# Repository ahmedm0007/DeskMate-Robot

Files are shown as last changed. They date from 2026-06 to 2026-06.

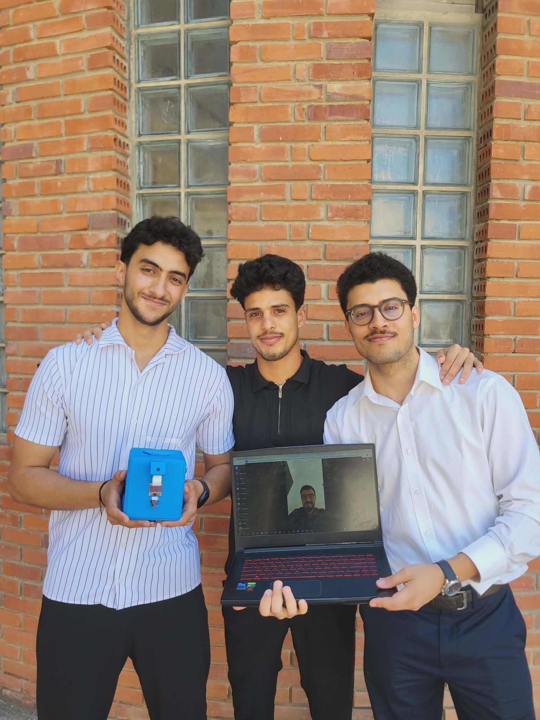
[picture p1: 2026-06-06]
our pic.jpg

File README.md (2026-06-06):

# 🤖 DeskMate — Intelligent Study Assistant Robot

> A physical desktop robot that monitors student concentration in real time, detects distraction and fatigue, and provides personalized academic assistance through voice interaction and AI-powered document Q&A.

---

## 📌 Overview

DeskMate is an end-of-year engineering project built at **INSAT** (National Institute of Applied Science and Technology, Tunis). It addresses a concrete problem: study sessions are rarely as effective as they should be. Students get distracted, lose focus, and have no tool that actively intervenes.

DeskMate is a **physical companion robot** — present on your desk like a lamp — that observes, analyzes, and acts. Unlike passive apps, it adapts its behavior in real time to the student's actual state.

---

## ✨ Features

### 👁️ Behavioral Monitoring (Vision Pipeline)
- **Real-time face detection** and multi-user recognition (MediaPipe + ArcFace/DeepFace)
- **Fatigue detection** via Eye Aspect Ratio (EAR) and Mouth Aspect Ratio (MAR)
- **Distraction detection**: gaze direction (head pose estimation) + smartphone detection (YOLOv8)
- **Absence detection**: alerts when the student leaves the camera field
- Runs at **~30 FPS** on Raspberry Pi 4, well within the 500ms real-time constraint

### 🗣️ Voice Interaction (Vocal Pipeline)
- **Wake word detection** (local, via Vosk) → **Speech-to-Text** (Google Web Speech API)
- **LLM-powered intent classification** and conversational responses (Qwen2.5-7B-Instruct via Hugging Face API)
- **Text-to-Speech** output (edge_tts + pygame) with ~0.8s generation time
- End-to-end latency: **2–4 seconds** for a complete voice exchange

### 📚 Academic AI Assistant (RAG System)
- Upload your own **PDF course documents**
- Hybrid search: **semantic (ChromaDB)** + **keyword (BM25)** retrieval
- Answers generated by **Gemini 2.5 Flash**, grounded exclusively in your documents
- Evaluation results: **85% answer correctness**, 87.5% hit rate on test corpus

### 📅 Adaptive Study Planner
- Input your subjects, mastery level, exam dates, and available hours
- Generates a **personalized weekly revision schedule** using a priority scoring model
- Urgency factor recalculated daily as exams approach
- Subjects automatically removed after their exam date

### 📊 Session Management & Dashboard
- Supports **Pomodoro**, **Deep Work**, and **52/17** productivity techniques
- Voice-controlled session start/pause/stop
- OLED display shows current state (focused / distracted / break / session end)
- **React/Next.js web dashboard** (localhost): session history, productivity graphs, planning, PDF upload

### 🚗 Autonomous Mobility
- **Differential drive** (2× GA12-N20 motors) controlled by ESP32
- **ToF sensor (VL53L0X)** for desk-edge detection and collision avoidance
- Autonomous repositioning to keep the student in camera frame

---

## 🏗️ System Architecture

```
┌─────────────────────────────────────────────────────┐
│            LAYER 1 — Perception                     │
│   Pi Camera 8MP | INMP441 Mic (I2S) | ToF VL53L0X  │
└────────────────────┬────────────────────────────────┘
                     │
┌────────────────────▼────────────────────────────────┐
│          LAYER 2 — AI Processing                    │
│  OpenCV + YOLOv8 + MediaPipe (Vision)               │
│  Vosk + Google STT (Speech)                         │
│  LLM (Qwen2.5) + RAG (LangChain + ChromaDB)         │
└────────────────────┬────────────────────────────────┘
                     │
┌────────────────────▼────────────────────────────────┐
│       LAYER 3 — Decision & Orchestration            │
│       FastAPI — State machine | Scheduler | Rules   │
└────────────────────┬────────────────────────────────┘
                     │
┌────────────────────▼────────────────────────────────┐
│            LAYER 4 — Actuators                      │
│    GA12-N20 Motors | OLED SSD1306 | Speaker (TTS)   │
└────────────────────┬────────────────────────────────┘
                     │
┌────────────────────▼────────────────────────────────┐
│         LAYER 5 — User Interface (localhost)        │
│         React / Next.js + Tailwind CSS              │
│   History | Charts | Planning | PDF Upload | Profiles│
└─────────────────────────────────────────────────────┘
```

---

## 🔧 Hardware

| Component | Role |
|---|---|
| Raspberry Pi 4 (4GB) | Main brain — runs all AI/software modules |
| ESP32 | Spinal cord — real-time actuator control |
| Pi Camera Module V2 (8MP) | Vision pipeline input |
| INMP441 Microphone (I2S) | Voice capture |
| MAX98357A Amplifier + 8Ω Speaker | TTS audio output |
| OLED Display SSD1306 (0.96") | Real-time status display |
| ToF Sensor VL53L0X | Desk-edge detection |
| 2× GA12-N20 DC Motors + TB6612FNG | Differential drive |
| 2× 18650 Li-ion (3000 mAh) + XL4015 Buck | Power supply (~2.5–3.5h autonomy) |
| 3D-printed PLA chassis | 3-level structure, custom-designed |

---

## 💻 Tech Stack

**AI & Vision**
`OpenCV` `MediaPipe` `YOLOv8` `DeepFace (ArcFace)` `LangChain` `ChromaDB` `BM25` `Gemini 2.5 Flash` `Qwen2.5-7B`

**Speech**
`Vosk` `Google Web Speech API` `edge_tts` `pygame`

**Backend**
`FastAPI` `Python 3.10+` `SQLite` `PostgreSQL`

**Frontend**
`React 19` `Next.js` `TypeScript` `Tailwind CSS v4` `Recharts` `Vite`

**Embedded**
`Raspberry Pi OS` `ESP32 (Arduino)` `pigpio` `I2C` `I2S` `UART` `PWM`

**Design**
`SolidWorks` (3D chassis) `KiCad` (PCB schematic)

---

## 📈 Performance Results

| Module | Metric | Result |
|---|---|---|
| Vision pipeline | Processing speed | ~30 FPS on RPi 4 |
| Behavioral detection | Latency | < 500ms ✅ |
| Face recognition (ArcFace) | Accuracy | > 99% |
| Phone detection (YOLOv8) | mAP@50 | 52.1% (+ temporal smoothing) |
| RAG system | Answer correctness | 85.0% |
| RAG system | Hit rate | 87.5% |
| Voice pipeline | End-to-end latency | 2–4 seconds |
| TTS (edge_tts) | Generation time | ~0.8 seconds |

---

## 👥 Team

| Name | Role |
|---|---|
| **MAMI Ahmed** | Embedded systems, hardware design, mechanical conception |
| **ZGHIBI Ahmed** | AI pipeline, system integration |
| **EL KADHI Mohamed Amine** | Vision & RAG modules |
| **ZNAGUI Wael** | Backend & dashboard |

**Supervisor:** Mme JAAFAR Imen  
**Institution:** INSAT — 4th year, Industrial Computing and Automation  
**Defended:** June 1st, 2026

---

## 📄 License

This project was developed as an academic end-of-year project at INSAT, Tunis. All rights reserved by the authors.

## 🗂️ Mechanical Files (SolidWorks)

Full 3D assembly and parts (SolidWorks + STL) are too large for GitHub.  
👉 [Download 3D Files (Google Drive)] https://drive.google.com/drive/folders/134jamOGdysIHbzPeDwZQ4sSwSuv-kNpy?usp=sharing

Includes:
- Full robot assembly (RobotAssemblageV1.SLDASM)
- All individual parts (SLDPRT)
- STL files for 3D printing
- KiCad PCB schematic

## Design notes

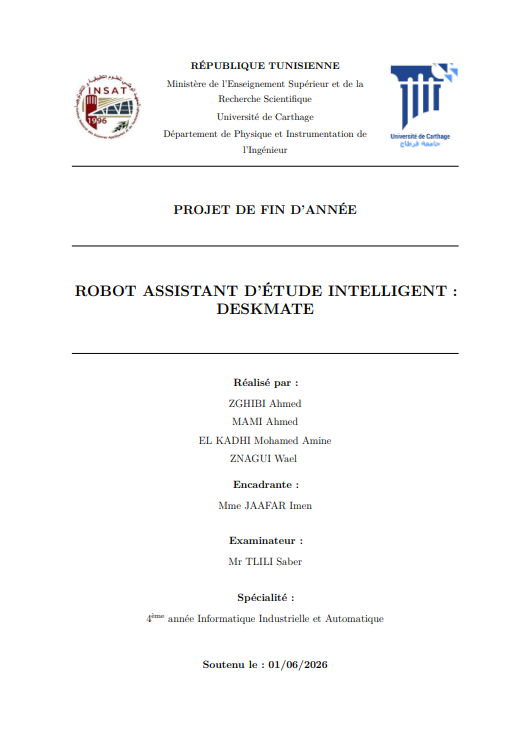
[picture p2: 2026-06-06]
firstRapportPage.png

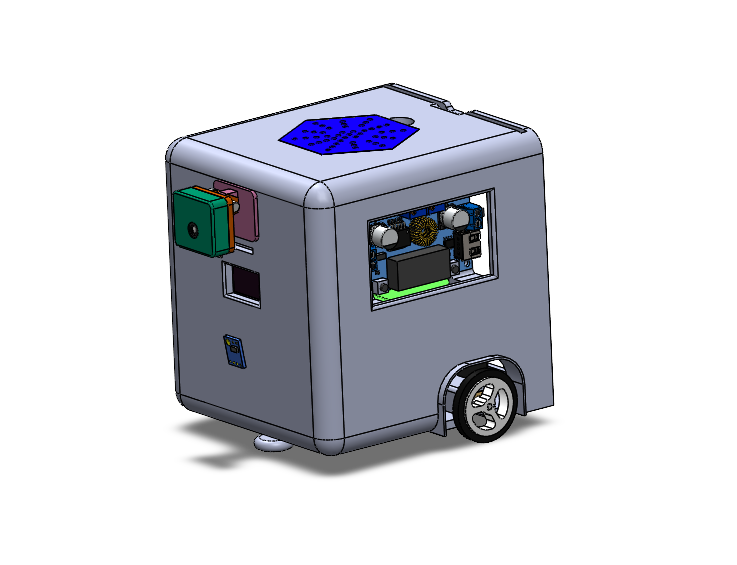
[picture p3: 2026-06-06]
RobotPIC.png

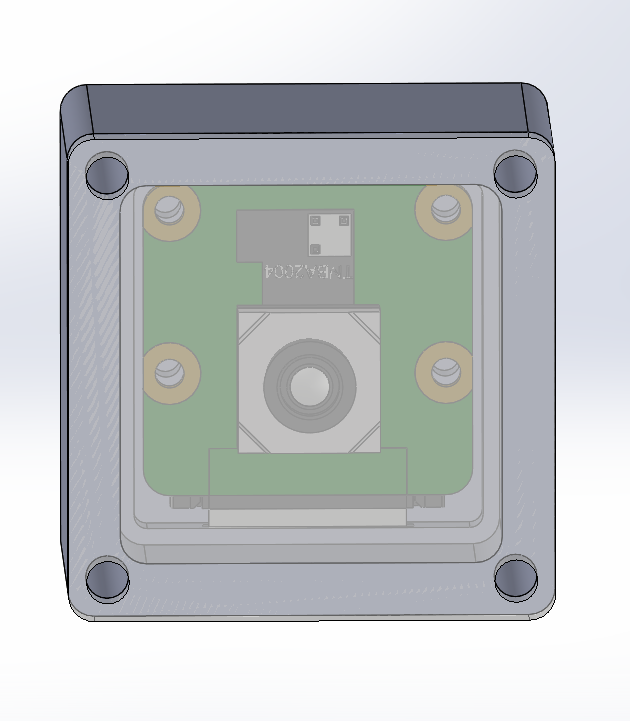
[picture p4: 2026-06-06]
MECANIQUE/picam holder/Screenshot 2025-12-24 074149.png

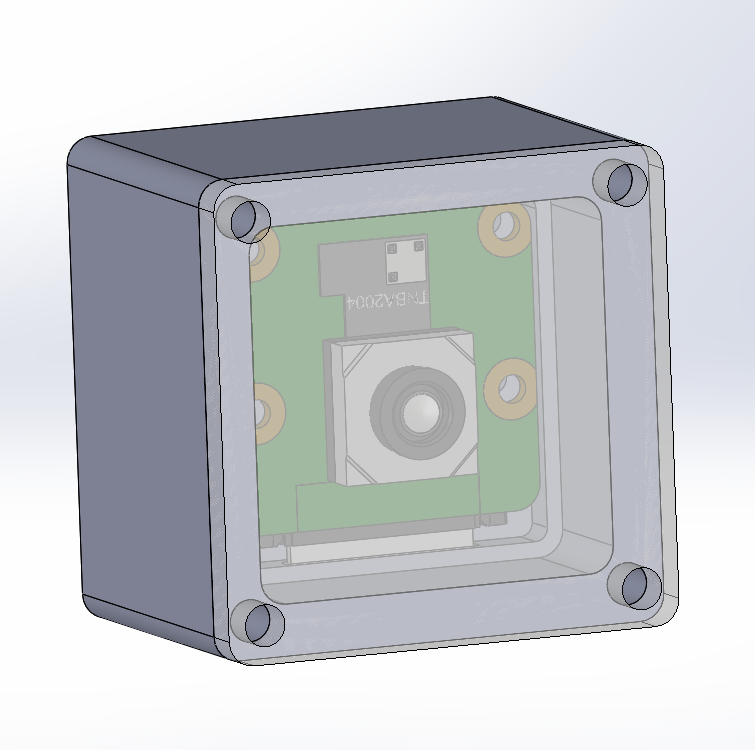
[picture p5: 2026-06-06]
MECANIQUE/picam holder/Screenshot 2025-12-24 074029.png

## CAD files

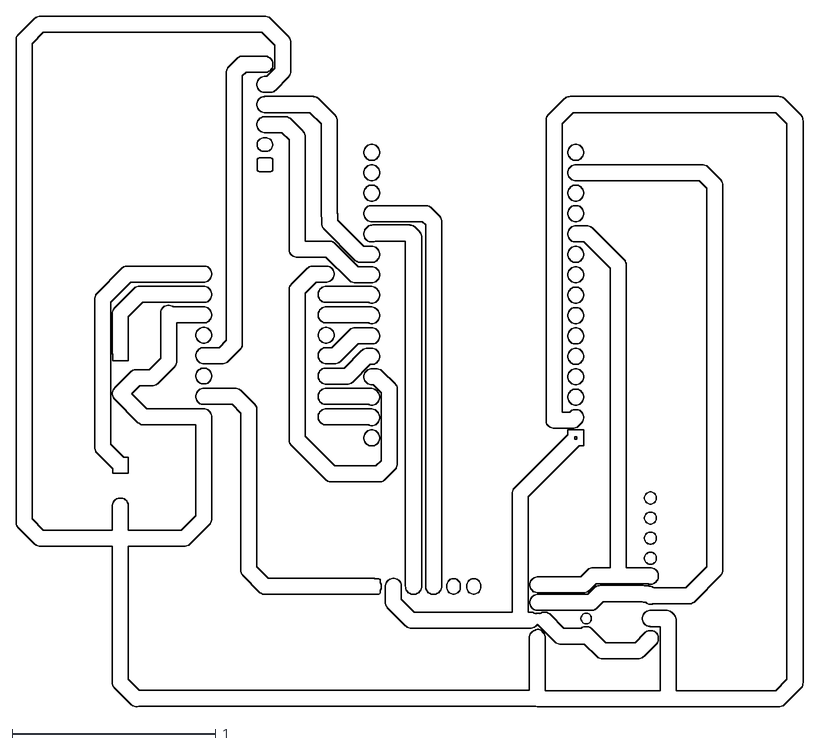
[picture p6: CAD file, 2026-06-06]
ELECTRIQUE/chimiqueV0/chimiqueV0-F_Cu.dxf
3.86 x 3.39

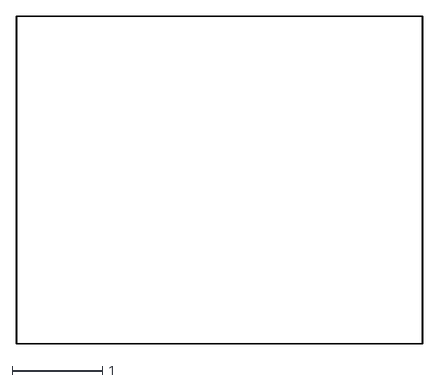
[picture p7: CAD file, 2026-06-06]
ELECTRIQUE/chimiqueV0/chimiqueV0-Edge_Cuts.dxf
4.49 x 3.62

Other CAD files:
ELECTRIQUE/chimiqueV0/chimiqueV0-Margin.dxf

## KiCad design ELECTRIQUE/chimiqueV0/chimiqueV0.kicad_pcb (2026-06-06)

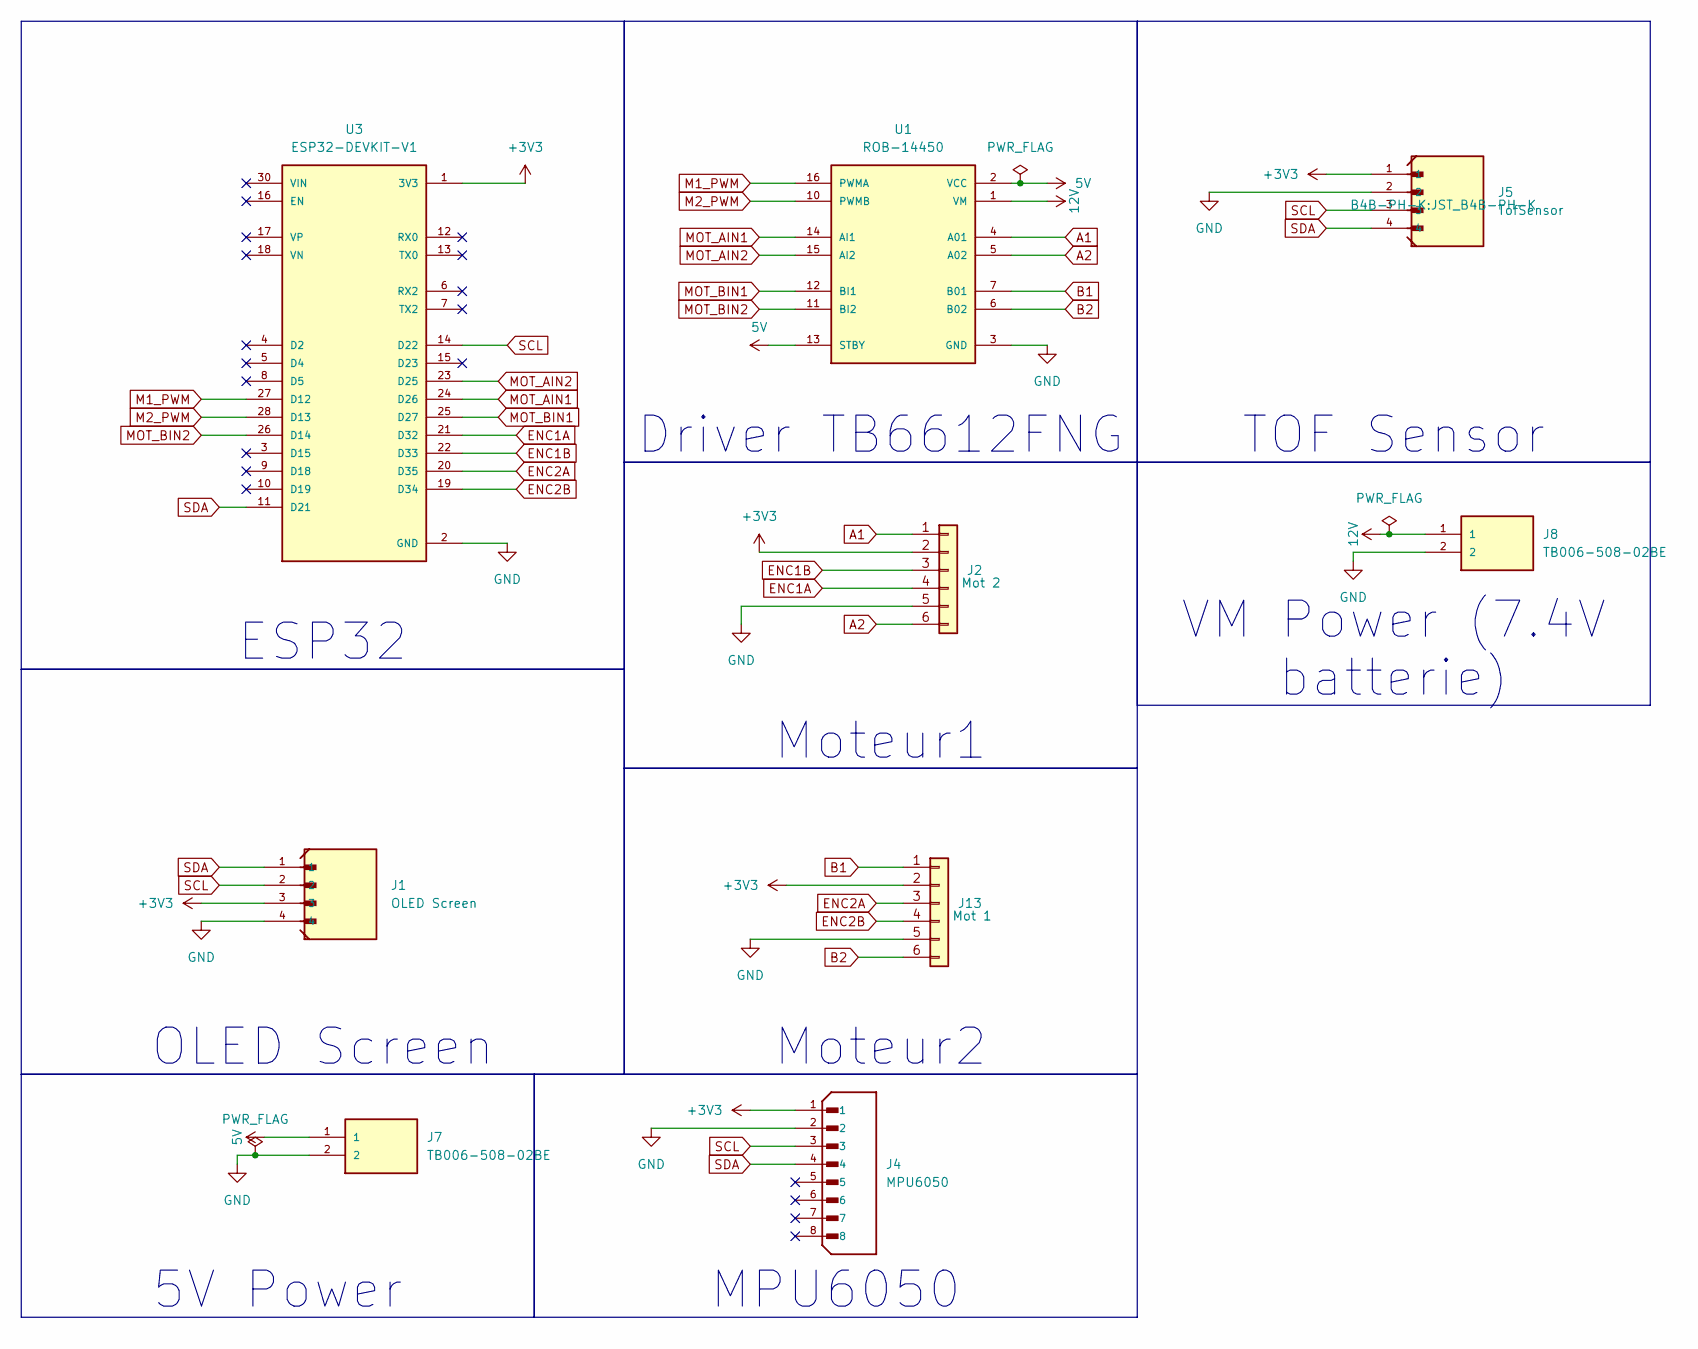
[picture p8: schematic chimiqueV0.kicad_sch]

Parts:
J1: OLED Screen; JST_B4B-PH-K
J2: Mot 2; JST_EH_B6B-EH-A_1x06_P2.50mm_Vertical
J4: MPU6050; JST_B8B-XH-A; PARTREV 7/4/21
J5: TofSensor; JST_B4B-PH-K
J7, J8: TB006-508-02BE; CUI_TB006-508-02BE
J13: Mot 1; JST_EH_B6B-EH-A_1x06_P2.50mm_Vertical
U1: ROB-14450; MODULE_ROB-14450; PARTREV 11-13-17
U3: ESP32-DEVKIT-V1; MODULE_ESP32_DEVKIT_V1; PARTREV N/A

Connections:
5V: J7.1, U1.2 (VCC), U1.13 (STBY)
12V: J8.1, U1.1 (VM)
+3V3: J1.3, J2.2, J4.1, J5.1, J13.2, U3.1 (3V3)
A1: J2.1, U1.4 (A01)
A2: J2.6, U1.5 (A02)
B1: J13.1, U1.7 (B01)
B2: J13.6, U1.6 (B02)
ENC1A: J2.4, U3.21 (D32)
ENC1B: J2.3, U3.22 (D33)
ENC2A: J13.3, U3.20 (D35)
ENC2B: J13.4, U3.19 (D34)
GND: J1.4, J2.5, J4.2, J5.2, J7.2, J8.2, J13.5, U1.3 (GND), U1.8 (GND), U1.9 (GND), U3.2 (GND), U3.29 (GND)
M1_PWM: U1.16 (PWMA), U3.27 (D12)
M2_PWM: U1.10 (PWMB), U3.28 (D13)
MOT_AIN1: U1.14 (AI1), U3.24 (D26)
MOT_AIN2: U1.15 (AI2), U3.23 (D25)
MOT_BIN1: U1.12 (BI1), U3.25 (D27)
MOT_BIN2: U1.11 (BI2), U3.26 (D14)
SCL: J1.2, J4.3, J5.3, U3.14 (D22)
SDA: J1.1, J4.4, J5.4, U3.11 (D21)

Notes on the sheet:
5V Power
Moteur2
ESP32
Driver TB6612FNG
Moteur1
MPU6050
OLED Screen
TOF Sensor
VM Power (7.4V batterie)

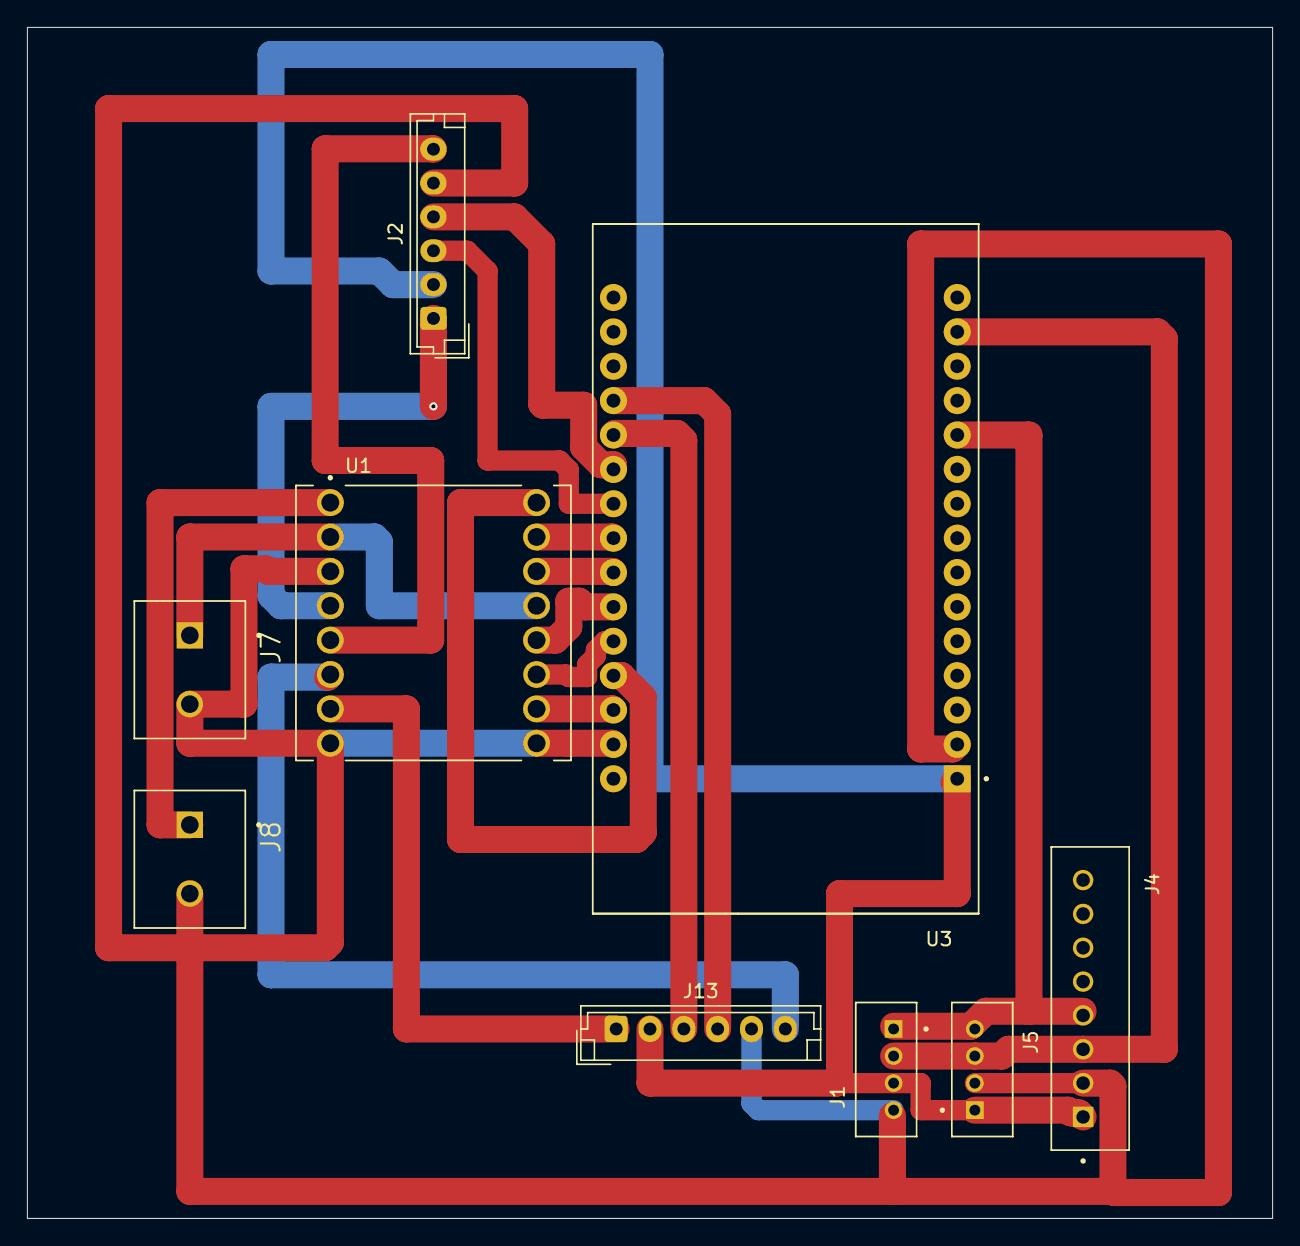
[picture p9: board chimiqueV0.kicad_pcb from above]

Board: 2 copper layers, 92.0 x 88.0 mm, 9 parts (0 on the bottom side), 20 nets.

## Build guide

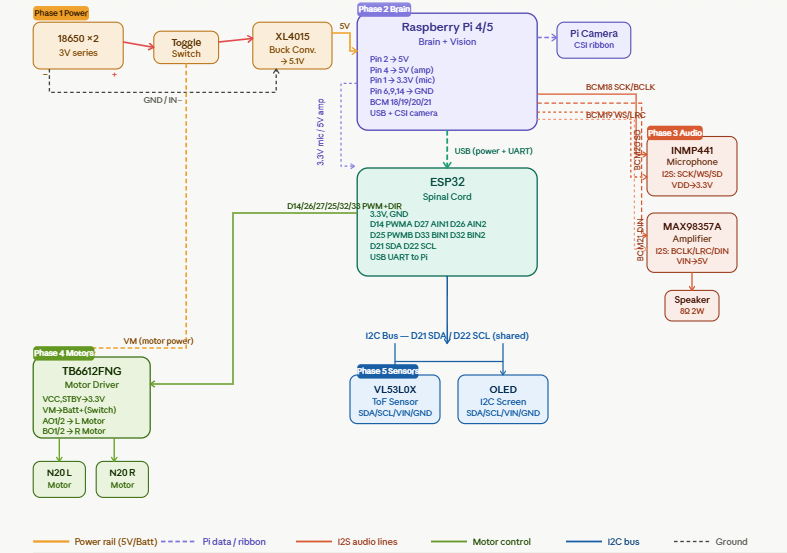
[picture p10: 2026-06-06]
ELECTRIQUE/WiringDiagram.png

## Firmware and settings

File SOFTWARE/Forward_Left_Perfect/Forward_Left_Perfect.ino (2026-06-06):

#include <Wire.h>
#include <Adafruit_GFX.h>
#include <Adafruit_SSD1306.h>

// ===================== OLED =====================
#define SCREEN_WIDTH 128
#define SCREEN_HEIGHT 64

Adafruit_SSD1306 display(SCREEN_WIDTH, SCREEN_HEIGHT, &Wire, -1);

// ===================== MOTOR PINS =====================
#define MOTOR_R_IN1 27
#define MOTOR_R_IN2 14
#define MOTOR_R_PWM 13

#define MOTOR_L_IN1 25
#define MOTOR_L_IN2 26
#define MOTOR_L_PWM 12

// ===================== ENCODERS =====================
#define ENCODER_RA 34
#define ENCODER_RB 35
#define ENCODER_LA 33
#define ENCODER_LB 32

volatile long encoderCount1 = 0;
volatile long encoderCount2 = 0;

// ===================== ROBOT =====================
#define WHEEL_DIAMETER_CM 3.4
#define ENCODER_PPR 12
#define GEAR_RATIO 30

#define TICKS_PER_REV (ENCODER_PPR * GEAR_RATIO)
#define CM_PER_TICK ((PI * WHEEL_DIAMETER_CM) / TICKS_PER_REV)
#define TICKS_PER_CM (TICKS_PER_REV / (PI * WHEEL_DIAMETER_CM))

// ===================== ENCODER ISR =====================
void IRAM_ATTR encoderISR1() {
  int b = digitalRead(ENCODER_RB);
  encoderCount1 += (b == HIGH) ? 1 : -1;
}

void IRAM_ATTR encoderISR2() {
  int b = digitalRead(ENCODER_LB);
  encoderCount2 += (b == HIGH) ? 1 : -1;
}

// ===================== MOTOR FUNCTIONS =====================
void motorsForward(int pwm) {
  digitalWrite(MOTOR_R_IN1, HIGH);
  digitalWrite(MOTOR_R_IN2, LOW);

  digitalWrite(MOTOR_L_IN1, HIGH);
  digitalWrite(MOTOR_L_IN2, LOW);

  ledcWrite(MOTOR_R_PWM, pwm);
  ledcWrite(MOTOR_L_PWM, pwm * 0.9);
}

void motorsStop() {
  digitalWrite(MOTOR_R_IN1, LOW);
  digitalWrite(MOTOR_R_IN2, LOW);

  digitalWrite(MOTOR_L_IN1, LOW);
  digitalWrite(MOTOR_L_IN2, LOW);

  ledcWrite(MOTOR_R_PWM, 0);
  ledcWrite(MOTOR_L_PWM, 0);
}

void turnLeft(int pwm) {
  // Right wheel forward
  digitalWrite(MOTOR_R_IN1, HIGH);
  digitalWrite(MOTOR_R_IN2, LOW);

  // Left wheel backward
  digitalWrite(MOTOR_L_IN1, LOW);
  digitalWrite(MOTOR_L_IN2, HIGH);

  ledcWrite(MOTOR_R_PWM, pwm);
  ledcWrite(MOTOR_L_PWM, pwm);
}

// ===================== DRIVE DISTANCE =====================
void driveDistance(float distanceCM, int pwm) {

  long targetTicks = distanceCM * TICKS_PER_CM;

  noInterrupts();
  encoderCount1 = 0;
  encoderCount2 = 0;
  interrupts();

  motorsForward(pwm);

  while (true) {

    long rightTicks = encoderCount1;
    long leftTicks  = encoderCount2;

    long avgTicks = (abs(rightTicks) + abs(leftTicks)) / 2;

    Serial.print("R=");
    Serial.print(rightTicks);
    Serial.print(" L=");
    Serial.print(leftTicks);
    Serial.print(" Target=");
    Serial.println(targetTicks);

    if (avgTicks >= targetTicks) {
      break;
    }

    delay(5);
  }

  motorsStop();
}

// ===================== TURN LEFT 90° =====================
void turnLeft90(int pwm) {

  noInterrupts();
  encoderCount1 = 0;
  encoderCount2 = 0;
  interrupts();

  long targetTicks = 220;

  turnLeft(pwm);

  while (true) {

    long r = abs(encoderCount1);
    long l = abs(encoderCount2);

    long avgTicks = (r + l) / 2;

    Serial.print("TURN=");
    Serial.println(avgTicks);

    if (avgTicks >= targetTicks) {
      break;
    }

    delay(5);
  }

  motorsStop();
}

// ===================== SETUP =====================
void setup() {
  Serial.begin(115200);

  // OLED
  if (!display.begin(SSD1306_SWITCHCAPVCC, 0x3C)) {
    Serial.println("OLED failed");
    while (true);
  }

  display.clearDisplay();
  display.display();

  // Motor pins
  pinMode(MOTOR_R_IN1, OUTPUT);
  pinMode(MOTOR_R_IN2, OUTPUT);
  pinMode(MOTOR_L_IN1, OUTPUT);
  pinMode(MOTOR_L_IN2, OUTPUT);

  ledcAttach(MOTOR_R_PWM, 5000, 8);
  ledcAttach(MOTOR_L_PWM, 5000, 8);

  // Encoder pins
  pinMode(ENCODER_RA, INPUT_PULLUP);
  pinMode(ENCODER_RB, INPUT_PULLUP);
  pinMode(ENCODER_LA, INPUT_PULLUP);
  pinMode(ENCODER_LB, INPUT_PULLUP);

  attachInterrupt(digitalPinToInterrupt(ENCODER_RA), encoderISR1, RISING);
  attachInterrupt(digitalPinToInterrupt(ENCODER_LA), encoderISR2, RISING);

  delay(1000);

  // Drive forward 30 cm
  driveDistance(30.0, 180);

  delay(500);

  // Turn left 90°
  turnLeft90(150);

  // Show message on OLED
  display.clearDisplay();
  display.setTextSize(1);
  display.setTextColor(SSD1306_WHITE);
  display.setCursor(10, 28);
  display.println("HALA MADRID");
  display.display();

  Serial.println("Mission complete");
}

// ===================== LOOP =====================
void loop() {
}

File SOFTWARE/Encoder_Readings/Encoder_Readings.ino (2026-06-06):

#define ENCODER_RA 34
#define ENCODER_RB 35
#define ENCODER_LA 33
#define ENCODER_LB 32

volatile long encoderCount1 = 0;
volatile long encoderCount2 = 0;


// --- Interrupts ---
void IRAM_ATTR encoderISR1() {
  int b = digitalRead(ENCODER_RB);
  encoderCount1 += (b == HIGH) ? 1 : -1;
}

void IRAM_ATTR encoderISR2() {
  int c = digitalRead(ENCODER_LB);
  encoderCount2 += (c == HIGH) ? 1 : -1;
}

void setup() {
  Serial.begin(115200);

  // --- Motor setup ---
  // --- Encoder setup ---
  pinMode(ENCODER_RA, INPUT_PULLUP);
  pinMode(ENCODER_RB, INPUT_PULLUP);
  pinMode(ENCODER_LA, INPUT_PULLUP);
  pinMode(ENCODER_LB, INPUT_PULLUP);

  attachInterrupt(digitalPinToInterrupt(ENCODER_RA), encoderISR1, RISING);
  attachInterrupt(digitalPinToInterrupt(ENCODER_LA), encoderISR2, RISING);

  encoderCount1 = 0;
  encoderCount2 = 0;
}

void loop() {
  // Read encoders safely
  long enc1 = encoderCount1;
  long enc2 = encoderCount2;
  Serial.print("Encoder_Right: "); Serial.print(enc1);
  Serial.print("  |Encoder_Left: "); Serial.println(enc2);

  delay(10);
}
